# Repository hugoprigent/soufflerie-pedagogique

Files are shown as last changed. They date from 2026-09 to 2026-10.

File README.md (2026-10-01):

# Soufflerie pédagogique — ENSAM, 2026

Cette soufflerie de table permet d'observer l'écoulement autour d'une maquette et d'étudier la commande du ventilateur, la mesure de force et l'acquisition vidéo sur Raspberry Pi. Le dépôt contient les modèles 3D, le logiciel et la documentation du banc.

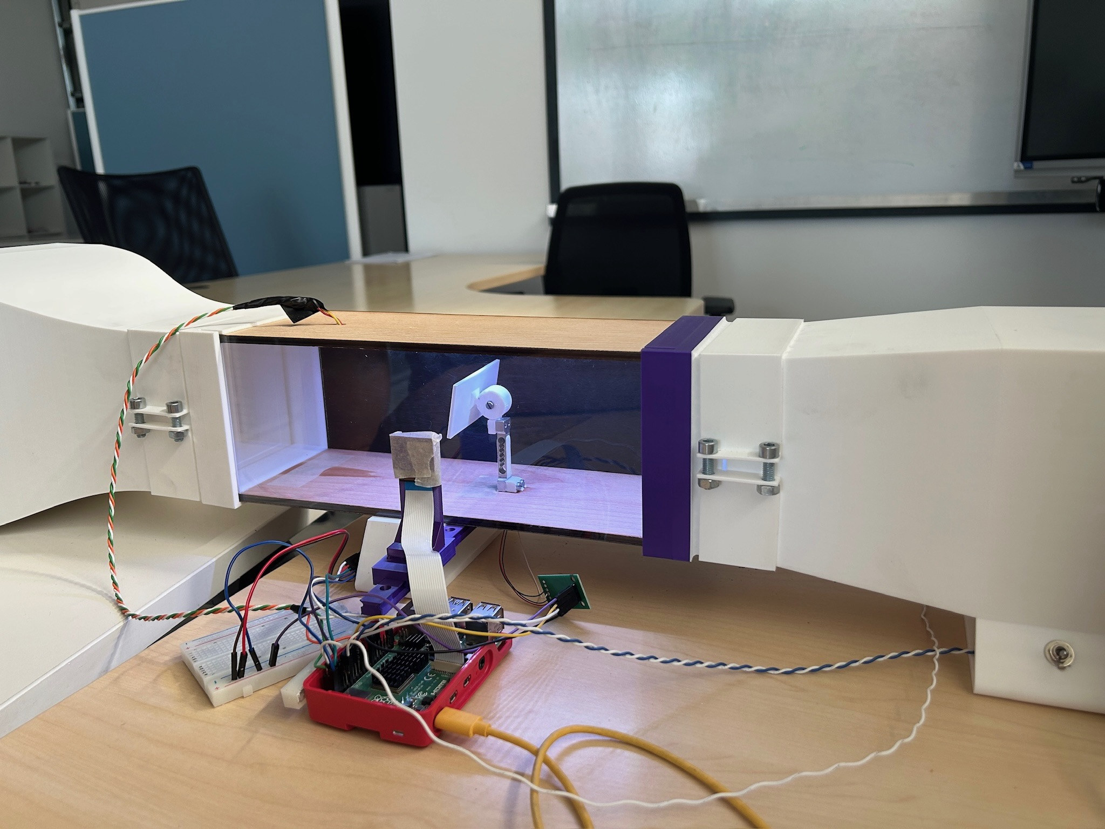
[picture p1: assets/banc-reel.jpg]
Soufflerie pédagogique avec section d'essai transparente


*La soufflerie avec sa section d'essai et son instrumentation.*

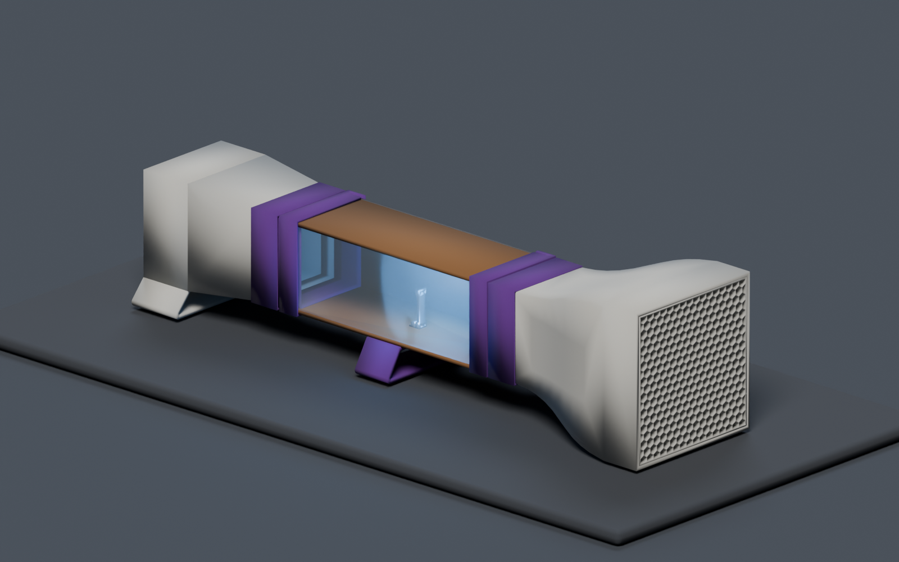
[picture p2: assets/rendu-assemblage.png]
Modèle 3D de la soufflerie


*Modèle 3D de la soufflerie : conduits, section d'essai et supports.*

## Vidéo de présentation

[Voir la soufflerie en vidéo sur YouTube](https://youtu.be/92m-7GADWI4).

## Le projet en bref

| Domaine | Ce qui est disponible |
| --- | --- |
| Mécanique | [Modèle 3D de la soufflerie](cad/assemblage-onshape.step), [23 modèles 3D des pièces](cad/step/), [modèle Blender](cad/rendu-assemblage.blend) et [guide de fabrication](cad/README.md) |
| Électronique | Raspberry Pi, ventilateur, cellule de charge et caméra ; [schéma de câblage](docs/schema-cablage.svg) et [documentation électronique](docs/electronique-cablage.md) |
| Logiciel | [Supervision Python](software/) : PWM et tachymètre, acquisition de force, caméra et traitement d'image, interface HTTP et export CSV |
| Données | [Un export de session](examples/session-2026-05-28.csv) avec [explication des colonnes et limites](docs/donnees-et-limites.md) |

Le banc comporte une section d'essai visible entre un convergent et un diffuseur. La maquette se place dans la veine ; la chaîne de force passe par une cellule de charge et le convertisseur HX711. Le tableau de bord affiche les signaux et permet la commande et l'enregistrement. La caméra sert à la visualisation et à un traitement de flux optique. Les valeurs de vitesse et les coefficients dérivés exigent une calibration indépendante avant toute interprétation quantitative.

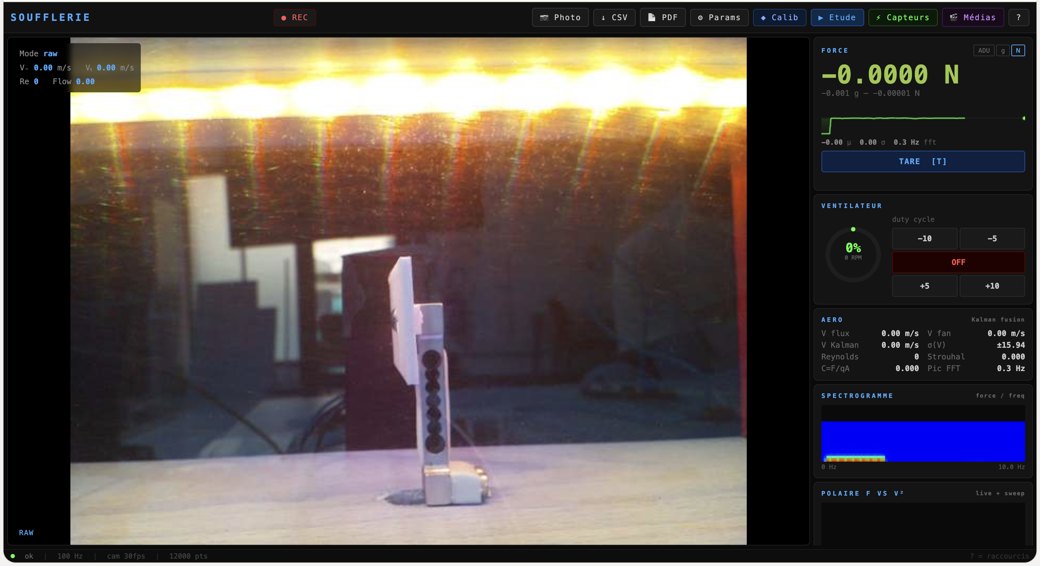
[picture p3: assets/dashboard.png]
Capture du tableau de bord avec retour caméra


*Capture du 28 mai 2026 : le ventilateur est à l'arrêt sur cette image.*

## Parcourir le dépôt

- [Reproduire le projet](docs/reproduire-le-projet.md) : fichiers 3D, nomenclature de reprise, ordre de fabrication, montage et points à relever sur le prototype.
- [CAO et fabrication](cad/README.md) : modèles de l'ensemble et des pièces, repères pour la fabrication.
- [Mécanique et assemblage](docs/mecanique-fabrication.md) : sous-ensembles visibles, ordre de montage proposé et vérifications avant fabrication.
- [Électronique et câblage](docs/electronique-cablage.md) : composants, connexions et broches du Raspberry Pi.
- [Installation et utilisation](docs/installation-utilisation.md) : environnement Raspberry Pi, lancement, accès local et sécurité réseau.
- [Données et limites](docs/donnees-et-limites.md) : ce que l'export permet d'examiner et ce qu'il ne valide pas.
- [Vérifications et compléments](docs/publication.md) : licence, câblage réel et validation matérielle.

## Calibration et accès

La vitesse d'air et les coefficients aérodynamiques affichés nécessitent un étalonnage indépendant.

Le serveur écoute par défaut sur `127.0.0.1:8080`. L'accès depuis un autre appareil doit être activé explicitement et limité à un réseau maîtrisé : l'application ne comporte pas d'authentification. Voir le [guide d'utilisation](docs/installation-utilisation.md).

## Réutilisation

Aucune licence de réutilisation n'est encore attribuée au code, à la documentation, aux photos ou aux modèles 3D. L'absence de fichier de licence ne vaut pas autorisation de réutilisation.

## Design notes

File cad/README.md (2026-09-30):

# CAO de la soufflerie

## Modèles 3D

- [Modèle 3D complet](assemblage-onshape.step) : soufflerie assemblée avec les composants à leur place.
- [23 modèles 3D des pièces](step/) : géométrie de chaque pièce de la soufflerie.

Le modèle complet montre la disposition des sous-ensembles. Les modèles individuels permettent d'examiner les pièces séparément.

Le [rendu 3D](../assets/rendu-assemblage.png) présente la soufflerie assemblée. Le [modèle Blender](rendu-assemblage.blend) permet de consulter cette vue en 3D. Les matériaux, fixations et tolérances de fabrication sont à préciser sur les plans des pièces.

## Pièces individuelles disponibles

Les noms des fichiers identifient notamment le cône de concentration, ses alvéoles, les deux diffuseurs, la fenêtre, les plaques de la veine, les pieds, les jonctions, les supports de caméra et de cellule de charge, un rail, une glissière et les volumes de représentation du ventilateur, de la caméra et de la cellule. Les suffixes `(1)` ne prouvent pas qu'il s'agit de variantes ou de pièces à fabriquer en double.

Certains modèles représentent des composants achetés ou des volumes d'encombrement. **Ne pas imprimer ou usiner l'ensemble des 23 fichiers sans tri.** La [nomenclature](../docs/mecanique-fabrication.md) détaille les pièces et sous-ensembles ; quantité, matériau et procédé doivent être déterminés pour chaque pièce à fabriquer.

## Pour fabriquer ou modifier

1. Ouvrir l'assemblage entier dans un logiciel CAO prenant en charge STEP AP242 et vérifier l'échelle, l'orientation, les corps et les interférences.
2. Comparer les zones de fixation et la section d'essai avec la photo du banc réel. Les modèles ne définissent ni tolérances, ni paramètres d'impression, ni ordre de montage.
3. Séparer les pièces fabriquées des composants commerciaux et contrôler chaque cote utile avant l'usinage ou l'impression.
4. Si une modification est faite dans Onshape, conserver la révision et réexporter à la fois l'assemblage et les pièces concernées.

Le lien Onshape éditable, la révision exacte, les matériaux pièce par pièce et les plans cotés restent à ajouter après vérification.

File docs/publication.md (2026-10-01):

# Vérifications et compléments à apporter

Ce dépôt présente le projet et ses fichiers de reprise. Les points suivants restent à décider ou à vérifier pour permettre une reproduction fidèle et une réutilisation claire :

1. **Licence et droits** — choisir une licence adaptée au code, aux modèles, aux textes et aux photos ; confirmer les droits de publication des éléments mécaniques.
2. **Câblage réel** — résoudre GPIO23/24 contre GPIO5/6 pour le HX711, déterminer la tension admise par la carte exacte et confirmer l'étage de commande du ventilateur. Une photo du montage et un relevé hors tension sont nécessaires.
3. **CAO** — vérifier l'assemblage AP242 dans une CAO, la révision Onshape, les interférences, les quantités et les droits attachés aux modèles de composants commerciaux. Ajouter le lien Onshape éditable s'il doit être public.
4. **Installation** — refaire l'installation sur un Raspberry Pi OS identifié et exécuter une démonstration contrôlée avec caméra, PWM, tachymètre, HX711 et export CSV.
5. **Mesure** — documenter les références de calibration, répétabilité et incertitudes avant de présenter des performances ou des coefficients expérimentaux.
6. **Visuels** — relire les photos pour tout élément personnel ou institutionnel visible ; la photo présente ici a été nettoyée de ses métadonnées EXIF.

L'archive documentaire privée, les factures, les paniers fournisseurs, les rapports de travail comportant des résultats non établis et les documents de tiers ne font pas partie du dépôt.

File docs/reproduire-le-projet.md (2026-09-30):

# Reproduire la soufflerie

Ce guide rassemble les fichiers et les contrôles nécessaires pour refaire un banc de même architecture. La [photo du prototype](../assets/banc-reel.jpg) et l'[assemblage STEP](../cad/assemblage-onshape.step) montrent l'état documenté ; ils ne donnent pas encore un plan de fabrication entièrement coté ni un câblage certifié. Conserver la traçabilité des choix faits lors d'une reproduction.

## Dossier de départ

| Besoin | Fichier | Usage |
| --- | --- | --- |
| Position des pièces | [Assemblage STEP](../cad/assemblage-onshape.step) | Ouvrir dans un logiciel CAO, inspecter les interfaces et mesurer les cotes utiles. |
| Géométrie de chaque pièce | [23 STEP séparés](../cad/step/) | Préparer les plans, l'impression ou l'usinage selon la pièce. |
| Aspect et vue d'ensemble | [Photo](../assets/banc-reel.jpg) et [modèle 3D](../assets/rendu-assemblage.png) | Voir la soufflerie et ses principaux sous-ensembles. |
| Logiciel | [Tableau de bord et modules](../software/) | Reprendre les fonctions GPIO, caméra, affichage et export. |
| Câblage | [Schéma de reprise](schema-cablage.svg) et [notes électriques](electronique-cablage.md) | Relever les connexions réelles puis établir un schéma final. |

## Nomenclature de reprise

Les quantités des pièces CAO sont à extraire de l'assemblage positionné, et les références achetées à lire sur le banc. Les éléments ci-dessous forment une **liste de familles**, pas un panier d'achat validé.

| Famille | Éléments identifiés | À renseigner avant achat ou fabrication |
| --- | --- | --- |
| Conduits et veine | Cône de concentration, alvéoles, diffuseur, jonctions, plaques dessus/dessous/fond, fenêtre, colliers | Dimensions internes, matière, épaisseur, procédé, état de surface, étanchéité |
| Structure et mesure | Pieds, rail, glissière, support de cellule de charge, support et maintien caméra | Positions, tolérances d'ajustement, visserie par liaison, reprise des efforts |
| Ventilation | Ventilateur représenté comme « 120x12x38 » dans le nom d'un STEP | Référence réelle, dimensions vérifiées, tension, courant, nombre de fils, brochage |
| Acquisition | Raspberry Pi, caméra, cellule de charge, carte HX711 | Référence des cartes et connecteurs, plage de mesure, tension et niveaux logiques |
| Éléments éventuels | Capteur BMP280/BME280, encodeur Modulino, LED | Présence réelle et nécessité pour la version à refaire |
| Alimentation et liaisons | Alimentations adaptées, fils, connecteurs, protection, fixations | Schéma électrique final, courant disponible, masse, isolation et cheminement des câbles |

Une nomenclature historique cite une fenêtre en polycarbonate et de la visserie M2, M3 et M5. Ces indications doivent être recoupées avec la version réellement fabriquée ; le dépôt ne donne pas encore les longueurs ni les quantités de vis.

## Séquence de reproduction

1. **Définir la version.** Comparer le [STEP d'assemblage](../cad/assemblage-onshape.step) à la photo. Lister les pièces à fabriquer, les pièces achetées et les écarts observés.
2. **Extraire les plans.** Mesurer dans la CAO les sections d'entrée et d'essai, les interfaces des conduits, l'épaisseur de fenêtre, les trous, les positions de rail et les dégagements autour du ventilateur et de la maquette. Ajouter tolérances et matériaux à des plans d'atelier avant fabrication.
3. **Préparer les pièces.** Utiliser les STEP séparés selon le procédé retenu. Faire un montage à blanc des plaques, de la fenêtre, des jonctions et des conduits ; vérifier alignement, étanchéité et accès à la section d'essai.
4. **Installer l'instrumentation.** Monter la cellule de charge sans effort parasite, puis caméra et éclairage. Vérifier que les fils ne traversent pas le flux ou ne touchent pas les pièces mobiles.
5. **Relever l'électricité.** Photographier les références et sérigraphies des cartes. Hors tension, suivre chaque fil du ventilateur, du HX711, de la cellule, de la caméra et du GPIO. Compléter le [schéma de reprise](schema-cablage.svg) en un schéma validé pour les composants choisis.
6. **Vérifier avant mise sous tension.** Confirmer polarités, alimentation séparée du moteur, masse de référence, niveaux logiques, protections, continuité et absence de court-circuit. Faire contrôler ce relevé par une personne compétente.
7. **Installer le logiciel.** Suivre le [guide Raspberry Pi](installation-utilisation.md), adapter les GPIO et les références dans `software/config.py`, puis tester les périphériques un par un avant de lancer l'application complète.
8. **Étalonner et documenter.** Tare et masses connues pour la chaîne de force ; référence indépendante pour la vitesse. Conserver les valeurs d'étalonnage, le montage, la date et les incertitudes avec les [données](donnees-et-limites.md).

## Informations à compléter pour une réplique fidèle

- Cotes critiques, tolérances, matières, procédés et fichiers de plans cotés.
- Nomenclature avec quantités, références commerciales, visserie et photos de chaque connexion.
- Schéma électrique vérifié du banc, surtout tension du HX711, niveau du tachymètre et mode de commande du ventilateur.
- Procédure d'étalonnage avec étalons, résultats et incertitudes ; essais sur Raspberry Pi et sur le banc assemblé.

Ces lacunes sont indiquées pour éviter qu'une hypothèse issue du logiciel ou d'une ancienne note soit prise pour une mesure sur le prototype.

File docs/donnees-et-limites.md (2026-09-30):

# Données et limites des essais

Le fichier [`examples/session-2026-05-28.csv`](../examples/session-2026-05-28.csv) est un export de session existant. Les lignes `#` enregistrent des paramètres au moment de l'export ; la ligne suivante nomme les colonnes. Il permet de voir la structure des acquisitions, sans constituer à lui seul une validation métrologique.

| Colonne | Sens dans l'export |
| --- | --- |
| `t_s` | Temps enregistré par l'acquisition, en secondes |
| `duty_pct` | Consigne PWM du ventilateur |
| `fan_rpm` | Régime déduit du tachymètre, sous réserve d'une lecture correcte |
| `delta_adu` | Signal HX711 après retrait de l'offset, en unités numériques |
| `force_g`, `force_N` | Force calculée avec la tare et l'échelle enregistrées |
| `flow_mag_px` | Grandeur issue du traitement d'image |
| `airspeed_flow_ms` | Estimation de vitesse issue de l'image et de sa calibration |
| `airspeed_fan_ms` | Estimation de vitesse issue du modèle ventilateur |

Dans les premières lignes de cet export, `duty_pct` vaut 60 tandis que `fan_rpm` et les deux estimations de vitesse valent zéro. Cette divergence impose de contrôler le tachymètre, l'état du ventilateur et les temps de transition avant d'utiliser ces colonnes pour conclure sur un essai. Les métadonnées de calibration ne prouvent pas que la chaîne a été étalonnée avec une référence traçable.

Le régime du ventilateur ne donne pas directement la vitesse locale dans la veine. Le flux optique dépend de l'échelle en pixels, de l'éclairage, du traceur visible et du plan observé. La mesure de force dépend notamment de la tare, de la rigidité du montage, des contacts parasites et des perturbations électriques. Aucune précision, plage utile, répétabilité ni coefficient aérodynamique validé n'est revendiqué ici.

Des documents historiques mêlent données enregistrées, valeurs théoriques, corrections et simulations. Ils n'ont pas été repris comme preuves expérimentales. Une suite de validation devrait conserver séparément les lectures brutes, les références de calibration, les transformations, les incertitudes et les conditions de montage, puis comparer plusieurs essais reproductibles.

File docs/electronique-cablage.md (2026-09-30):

# Électronique et câblage

Schéma de reprise du câblage avec connexions du logiciel et points incertains

Le [schéma de reprise en SVG](schema-cablage.svg) accompagne le relevé du prototype. Les traits pleins montrent les affectations déclarées par le code ; les pointillés signalent les alimentations et connexions à confirmer avant de construire un circuit. Il ne constitue pas un schéma de mise sous tension validé.

## Chaîne fonctionnelle

```mermaid
flowchart LR
  P[Raspberry Pi] -->|PWM| V[Ventilateur]
  V -->|Tachymètre| P
  C[Cellule de charge] --> H[HX711] -->|DT / SCK| P
  K[Caméra] -->|CSI| P
  B[Capteur BMP280/BME280] -. I²C optionnel .-> P
  M[Encodeur Modulino] -. I²C optionnel .-> P
  P --> I[Interface web et CSV]
```

Le logiciel actuel utilise directement les GPIO pour lire le HX711 et commander le ventilateur. Il prévoit également un bus I²C et un ruban LED SPI. La présence et le branchement effectifs de tous les modules optionnels n'ont pas été revérifiés.

## Broches déclarées par le code actuel

| Fonction | GPIO BCM | Broche physique Raspberry Pi | Source |
| --- | ---: | ---: | --- |
| PWM ventilateur | 18 | 12 | `software/config.py` |
| Tachymètre ventilateur | 17 | 11 | `software/config.py` |
| HX711 DT | 23 | 16 | `software/config.py` |
| HX711 SCK | 24 | 18 | `software/config.py` |
| I²C SDA / SCL | 2 / 3 | 3 / 5 | Bus Raspberry Pi, modules I²C du code |
| Ruban LED SPI | 10 | 19 | `software/src/led_control.py` |

**Divergence importante :** des notes et rapports historiques placent HX711 DT/SCK sur GPIO5/6, tandis que le code courant et une note de connexions plus récente indiquent GPIO23/24. Une ancienne note demande une alimentation HX711 à 3,3 V ; une autre à 5 V pour un module supposé régulé. Le type exact de carte HX711 et le câblage réel ne sont pas établis par les sources disponibles. **Ne brancher le module ni à 3,3 V ni à 5 V d'après ce seul document.** Vérifier la référence, le schéma ou la sérigraphie de la carte et les niveaux logiques avant mise sous tension, puis aligner `config.py` sur le banc.

## Alimentations et interfaces à contrôler

- Le ventilateur a une alimentation distincte de celle du Raspberry Pi. Confirmer sa tension et son brochage sur la référence réellement montée. Ne pas alimenter le moteur depuis un GPIO.
- Les notes diffèrent sur l'étage de commande : PWM direct d'un ventilateur à quatre fils dans la note récente, MOSFET dans des documents plus anciens. Identifier le ventilateur et le montage présents avant de reproduire le circuit.
- Vérifier la masse de référence commune des signaux de commande, les niveaux d'entrée du tachymètre et l'état du ventilateur en cas de perte de PWM.
- La caméra se connecte à l'interface CSI du Pi ; l'orientation de la nappe doit être vérifiée sur les connecteurs effectivement utilisés.
- Les modules BMP280/BME280 et Modulino sont prévus sur le bus I²C ; vérifier leurs adresses et leur présence. Le capteur de pression seul ne suffit pas à établir une vitesse locale validée.

Aucun schéma historique n'est présenté comme plan de câblage définitif : certains portent GPIO5/6 et des hypothèses d'alimentation incompatibles avec les notes plus récentes. Le prochain contrôle utile est une photo nette de chaque carte, de ses fils et de l'en-tête GPIO, suivie d'un relevé point à point hors tension.

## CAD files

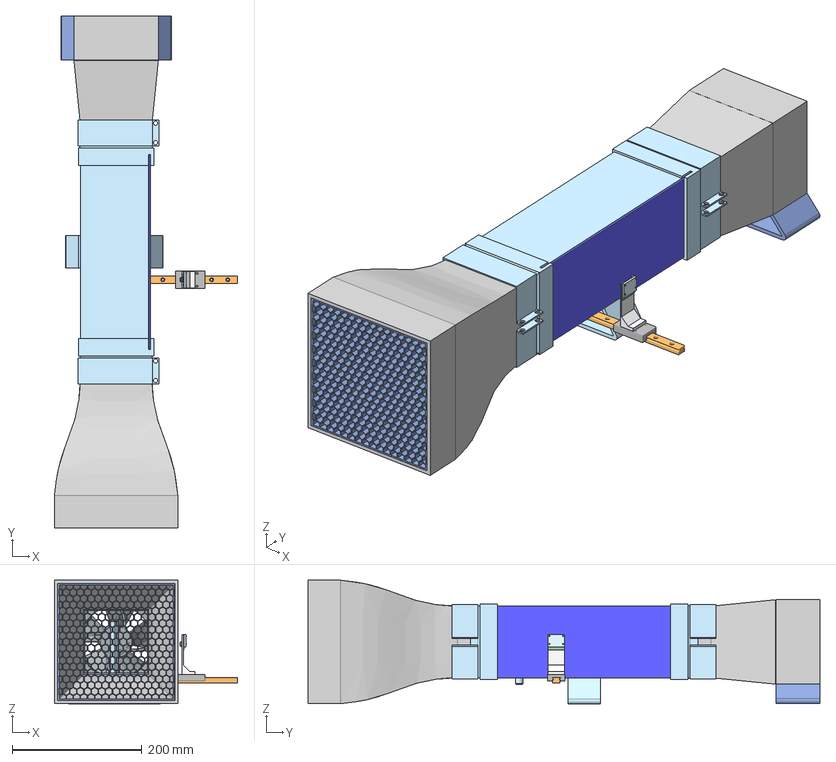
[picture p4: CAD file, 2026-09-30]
cad/assemblage-onshape.step
281.9 x 788.0 x 190.2 mm
Rail
Plaque dessus
Diffuseur x 2
Fenêtre
Alvéoles concentration
Jonction droite
Collier de serrage x 2
120x12x38 fan
Maintien caméra
Caméra
Support caméra
Glissière
Plaque dessous
Plaque fond
Pied diffuseur
Support cellule de charge
Jonction gauche
Cône de concentration
Alvéoles diffuseur
Cellule de charge

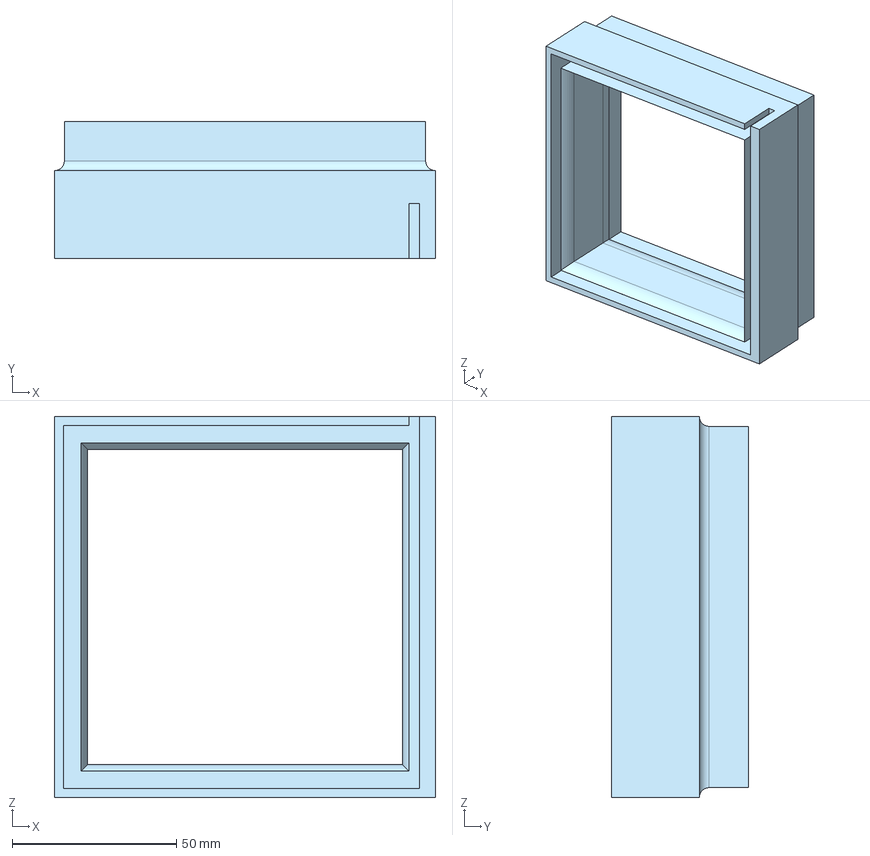
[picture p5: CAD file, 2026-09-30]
cad/step/Assemblage V2 - Jonction droite.step
116.0 x 41.8 x 116.0 mm

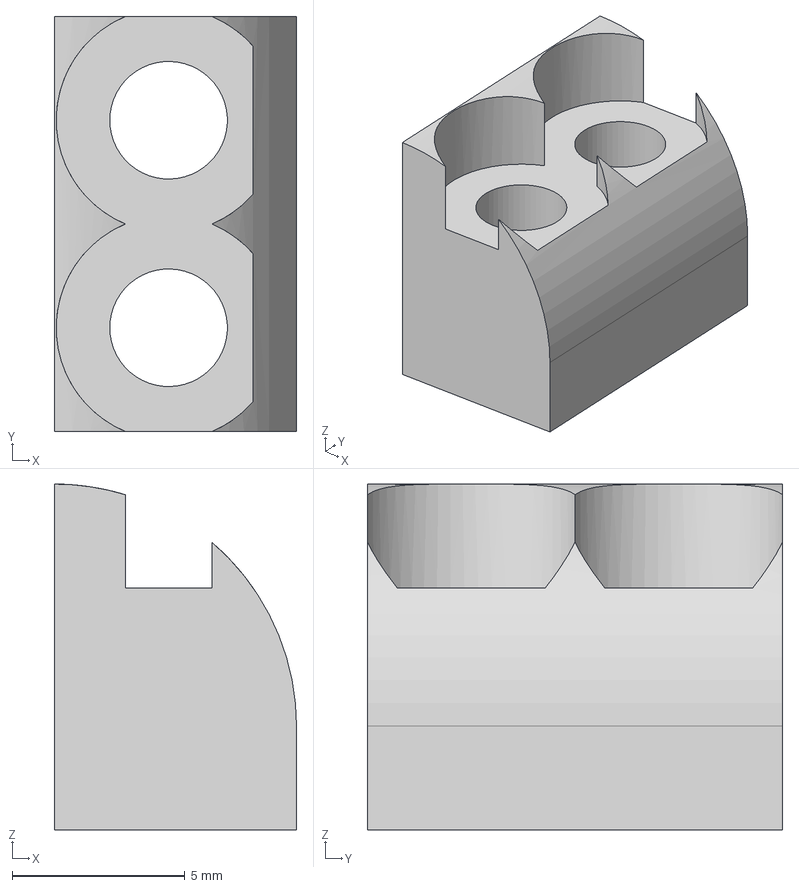
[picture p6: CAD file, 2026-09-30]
cad/step/Assemblage V2 - Support cellule de charge.step
7.00 x 12.0 x 10.0 mm

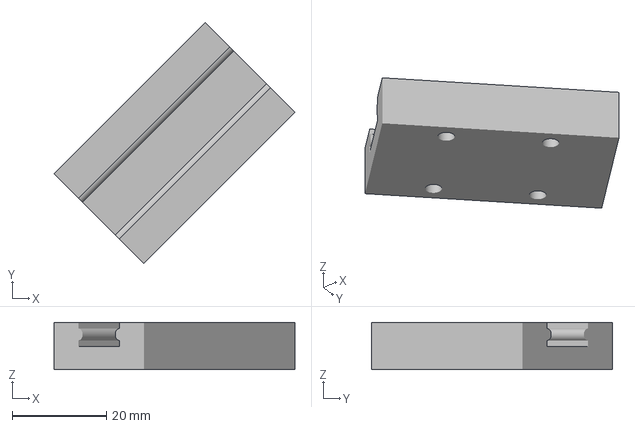
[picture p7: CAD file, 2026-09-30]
cad/step/Assemblage V2 - Glissière.step
51.2 x 51.2 x 10.0 mm

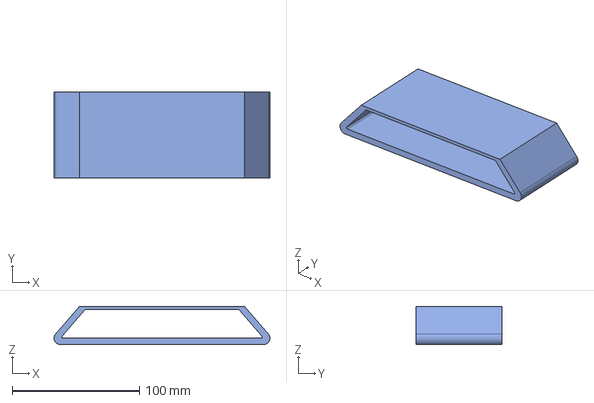
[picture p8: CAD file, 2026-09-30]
cad/step/Assemblage V2 - Pied diffuseur.step
170.0 x 68.0 x 30.0 mm

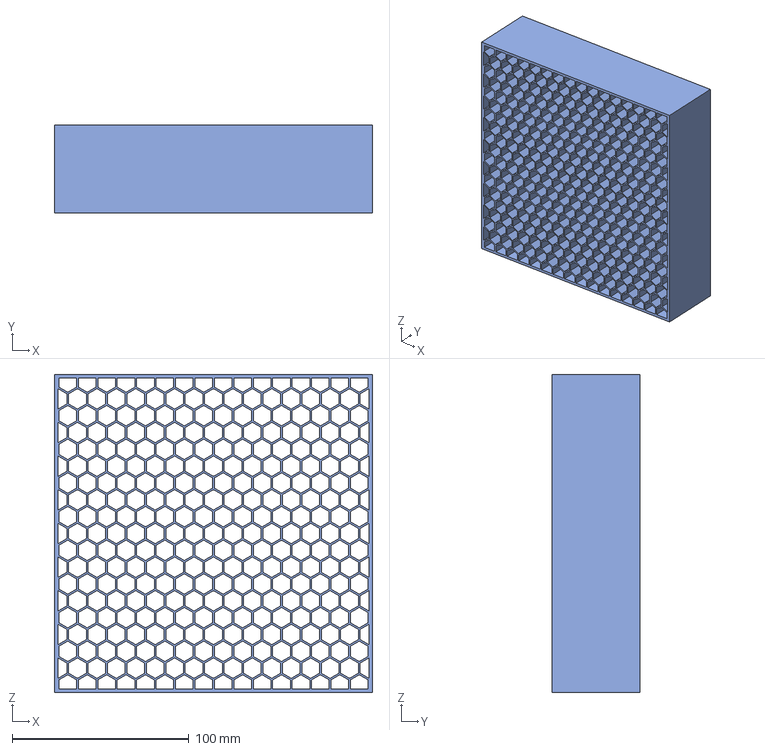
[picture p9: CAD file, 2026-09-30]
cad/step/Assemblage V2 - Alvéoles concentration.step
180.0 x 50.0 x 180.0 mm

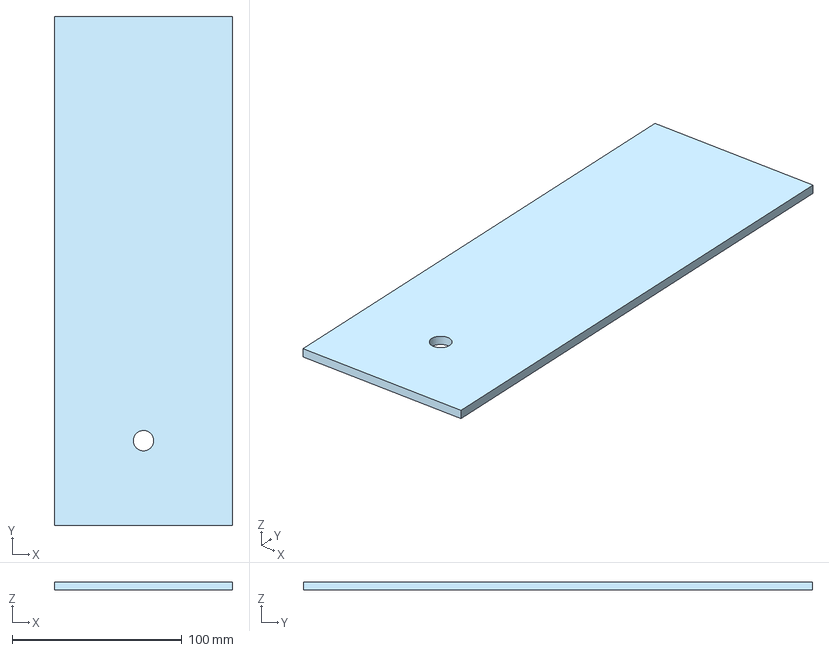
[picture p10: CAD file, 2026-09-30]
cad/step/Assemblage V2 - Plaque dessous.step
105.2 x 300.0 x 5.00 mm

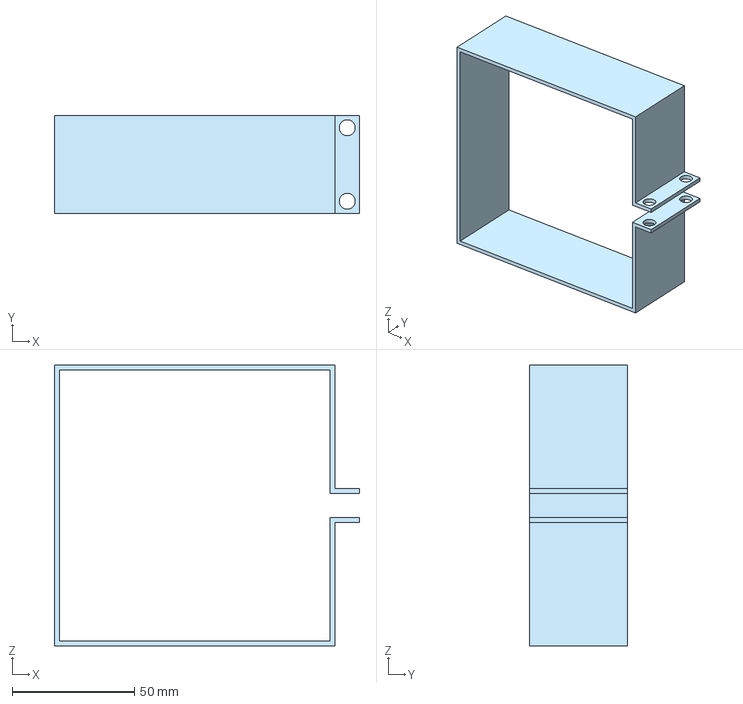
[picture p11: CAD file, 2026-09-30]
cad/step/Assemblage V2 - Collier de serrage.step
124.5 x 40.0 x 114.5 mm

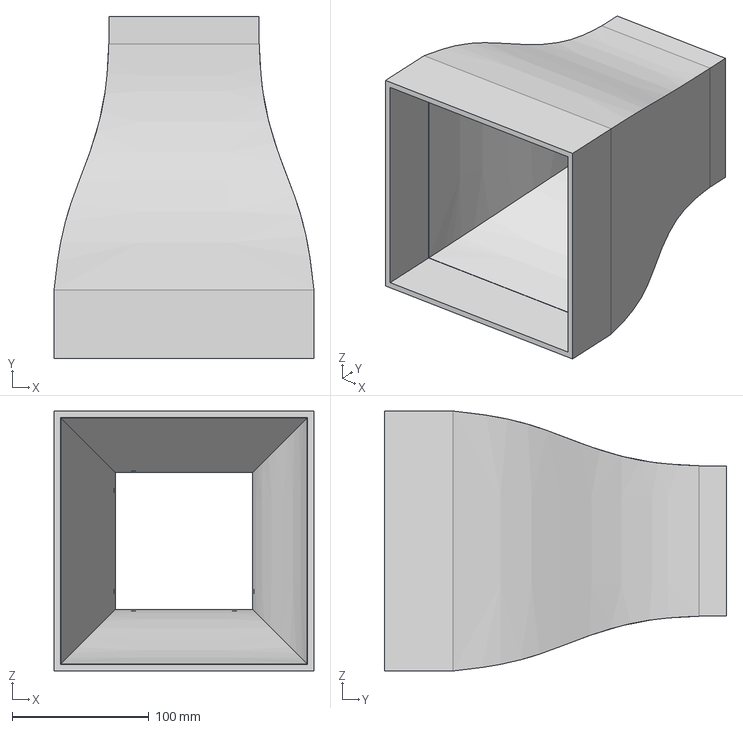
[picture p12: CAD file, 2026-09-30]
cad/step/Assemblage V2 - Cône de concentration.step
190.0 x 250.0 x 190.0 mm

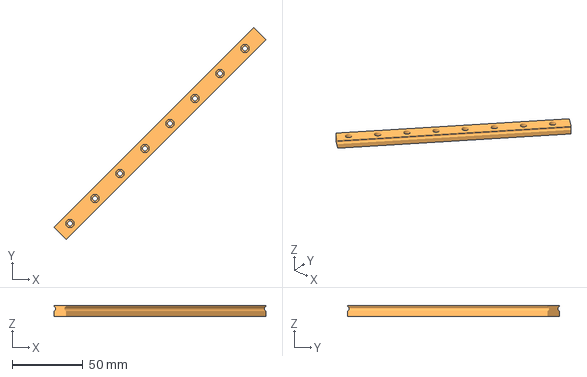
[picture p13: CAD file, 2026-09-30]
cad/step/Assemblage V2 - Rail.step
149.9 x 149.9 x 8.00 mm

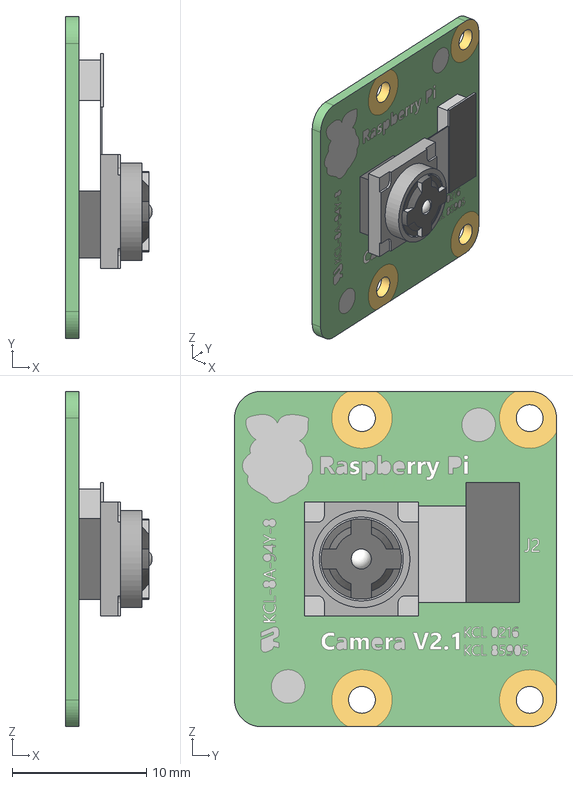
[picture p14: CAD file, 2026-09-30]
cad/step/Assemblage V2 - Caméra.step
6.45 x 24.0 x 25.0 mm

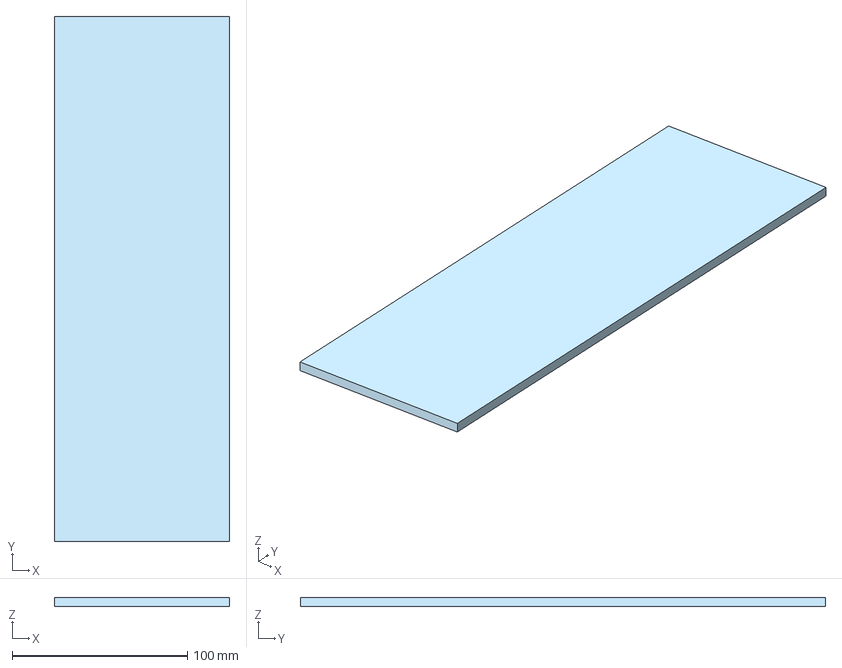
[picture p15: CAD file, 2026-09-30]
cad/step/Assemblage V2 - Plaque fond.step
100.0 x 300.0 x 5.00 mm

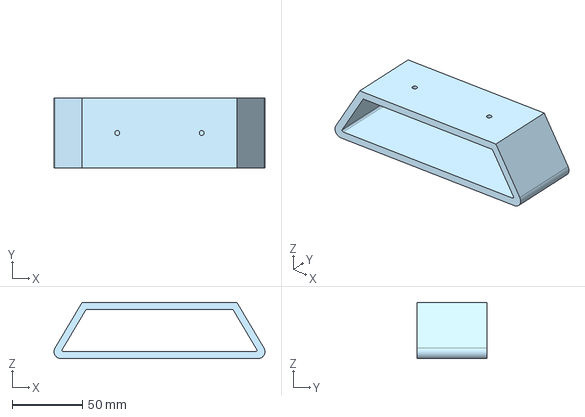
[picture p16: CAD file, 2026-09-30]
cad/step/Assemblage V2 - Pied section d'essai.step
150.0 x 50.0 x 40.0 mm

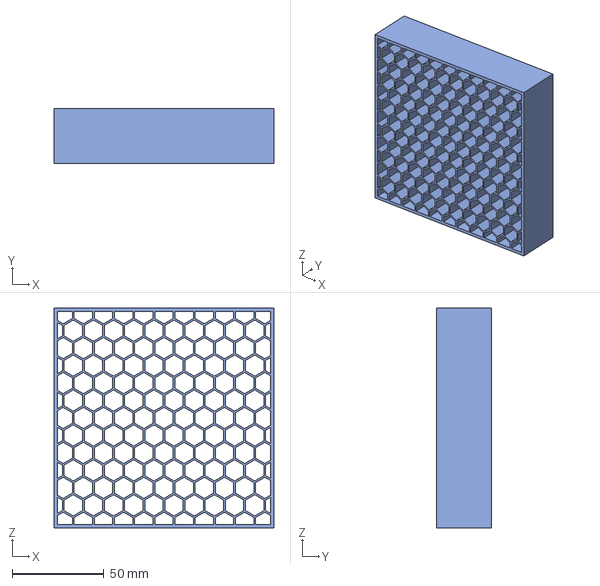
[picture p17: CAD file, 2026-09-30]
cad/step/Assemblage V2 - Alvéoles diffuseur.step
120.0 x 30.0 x 120.0 mm

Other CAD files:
cad/step/Assemblage V2 - Jonction gauche.step
cad/step/Assemblage V2 - Plaque dessus.step
cad/step/Assemblage V2 - 120x12x38 fan.step
cad/step/Assemblage V2 - Maintien caméra.step
cad/rendu-assemblage.blend
cad/step/Assemblage V2 - Cellule de charge.step
cad/step/Assemblage V2 - Collier de serrage (1).step
cad/step/Assemblage V2 - Diffuseur (1).step
cad/step/Assemblage V2 - Diffuseur.step
cad/step/Assemblage V2 - Fenêtre.step
cad/step/Assemblage V2 - Support caméra.step

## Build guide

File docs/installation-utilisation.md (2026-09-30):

# Installation et utilisation sur Raspberry Pi

## Portée

Le point d'entrée est `software/dashboard.py`. Il initialise des GPIO, le ventilateur, la caméra et des boucles d'acquisition dès son lancement. Il ne s'exécute donc pas comme une simple application web sur un ordinateur sans matériel. La procédure ci-dessous est une base de reprise, **non validée sur une image Raspberry Pi OS neuve**.

La [documentation Raspberry Pi OS](https://www.raspberrypi.com/documentation/computers/os.html#use-python-on-a-raspberry-pi) recommande `apt` pour les paquets système et un environnement virtuel pour les dépendances `pip`. La [documentation caméra officielle](https://www.raspberrypi.com/documentation/computers/camera_software.html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) décrit l'installation de Picamera2 via `apt`.

## Préparer le Pi

1. Vérifier le [câblage réel](electronique-cablage.md), en particulier le HX711 et l'étage ventilateur, avant de mettre le banc sous tension.
2. Installer Raspberry Pi OS et activer caméra, I²C et SPI selon les périphériques réellement présents. Vérifier la caméra avec les outils du système avant de lancer le tableau de bord.
3. Installer les modules système nécessaires, par exemple `python3-picamera2`, `python3-opencv`, `python3-numpy`, `python3-matplotlib`, `python3-rpi.gpio`, `python3-spidev`, `python3-venv` et `ffmpeg` pour les conversions vidéo. La disponibilité et la compatibilité de ces paquets dépendent de l'image choisie.
4. Depuis la racine de ce dépôt, créer l'environnement puis installer les dépendances Python restantes :

   ```sh
   python3 -m venv --system-site-packages .venv
   . .venv/bin/activate
   python -m pip install -r software/requirements.txt
   ```

5. Depuis `software/`, vérifier les valeurs de `config.py`, puis lancer `python dashboard.py`. Le répertoire de données est `software/data/` par défaut ; `SOUFFLERIE_DATA_DIR` permet de le déplacer. Les exports et calibrations restent locaux et sont ignorés par Git.

## Accès et sécurité réseau

Par défaut, le serveur écoute sur `127.0.0.1:8080`. Sur le Pi, ouvrir `http://127.0.0.1:8080`. Depuis un poste de confiance, un tunnel SSH permet de conserver cette écoute locale :

```sh
ssh -L 8080:127.0.0.1:8080 utilisateur@adresse-du-pi
```

Ouvrir ensuite `http://127.0.0.1:8080` sur le poste. Pour une démonstration sur un réseau isolé, l'opérateur peut définir `SOUFFLERIE_BIND_HOST=0.0.0.0` avant le lancement. **L'application n'a ni authentification ni chiffrement HTTP** ; cet accès donne aux autres clients du réseau la possibilité de commander le ventilateur, changer la calibration, agir sur des fichiers de session et voir le flux caméra. Ne pas l'exposer à Internet ou à un réseau partagé non maîtrisé. La configuration Wi-Fi depuis l'interface est désactivée par défaut ; elle demande `SOUFFLERIE_ENABLE_WIFI_CONTROL=1` et des droits NetworkManager configurés sur le Pi. Aucun mot de passe administrateur n'est stocké dans le code.

## Utiliser et enregistrer

1. Contrôler l'arrêt initial du ventilateur, l'image caméra et les indicateurs d'erreur.
2. Faire une tare et vérifier l'échelle de la cellule avec une référence connue, sans extrapoler de précision à partir d'une seule masse.
3. Vérifier séparément les estimations de vitesse. Les constantes de `config.py` sont des paramètres de départ, pas un étalonnage du banc assemblé.
4. Commander progressivement le ventilateur, surveiller les pièces libres et enregistrer une session.
5. À la fin, ramener la consigne à zéro, arrêter l'enregistrement et exporter les données.

Les dépendances déclarées par le projet historique utilisaient notamment des versions Python plus anciennes ; elles n'ont pas été réinstallées ni testées sur un Pi pour cette copie. `software/requirements.txt` ne contient que `smbus2`, utilisé pour l'I²C et à installer dans l'environnement virtuel ; les autres imports principaux sont fournis par les paquets système indiqués ci-dessus. Le module `hx711` historique a été retiré des dépendances : le tableau de bord lit le composant par GPIO directement.

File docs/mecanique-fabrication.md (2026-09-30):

# Mécanique et fabrication

## Architecture visible

La photo du prototype montre un convergent et un diffuseur blancs autour d'une section d'essai transparente. Les panneaux supérieur et inférieur paraissent en bois clair, le fond de la veine est sombre, et des éléments de liaison violets ferment les extrémités. Une maquette est portée dans la veine ; une caméra et un éclairage permettent l'observation. Les fils et le boîtier électronique restent apparents.

L'[assemblage STEP](../cad/assemblage-onshape.step) est la meilleure source disponible pour l'agencement CAO. Les [23 pièces STEP](../cad/step/) servent à examiner les formes séparément. Les modèles ne fournissent pas, à eux seuls, des plans de fabrication cotés avec tolérances ou une nomenclature validée.

## Repères de composants

Une nomenclature de l'assemblage historique cite un cône de concentration, des alvéoles, une section d'essai, deux colliers, un diffuseur, une fenêtre en polycarbonate, un pied et de la visserie M2, M3 et M5. Cet état historique peut différer de l'export V2, qui comporte par exemple plusieurs plaques, supports et jonctions. Il sert de repère pour le tri, **pas de liste de commande vérifiée**.

| Sous-ensemble | Fichiers ou éléments à examiner | Vérification nécessaire |
| --- | --- | --- |
| Entrée et sortie | Cône de concentration, alvéoles, diffuseur, pied diffuseur | Sens du flux, raccords, fixation au ventilateur |
| Veine d'essai | Plaques, fenêtre, jonctions, colliers | Dimensions internes, étanchéité, accès à la maquette |
| Instrumentation | Rail, glissière, support de cellule de charge, support et maintien caméra | Alignement, absence de contact parasite avec la veine |
| Composants achetés | Ventilateur, caméra, cellule de charge | Références exactes et encombrement réel |

## Ordre de montage proposé à vérifier sur le banc

1. Identifier les pièces réellement fabriquées et les pièces commerciales dans l'assemblage CAO.
2. Assembler à blanc les panneaux et la fenêtre de la veine ; contrôler l'alignement et les interfaces avec le convergent et le diffuseur.
3. Installer les supports, rail, maquette et cellule de charge sans contrainte latérale ni contact non prévu avec les parois.
4. Poser caméra et éclairage en conservant l'accès à la section d'essai.
5. Fixer ventilateur et conduits, puis contrôler le sens du flux, les dégagements des pales et l'absence de pièces libres.
6. Faire contrôler le câblage et les alimentations avant la mise sous tension.

Cet ordre décrit une méthode de préparation ; ce n'est pas un protocole d'atelier validé. Il manque encore les cotes critiques, tolérances, visserie par emplacement, paramètres d'impression et détails d'étanchéité.

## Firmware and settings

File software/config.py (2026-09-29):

# GPIO (BCM)
PIN_FAN_PWM = 18
PIN_FAN_TACH = 17
PIN_HX711_DT = 23
PIN_HX711_SCK = 24

# Modulino Knob I2C
MODULINO_I2C_ADDR = 0x3A

# Capteur pression BMP280 (I2C, même bus que Modulino)
# Câblage : SDA→GPIO2/Pin3, SCL→GPIO3/Pin5, VCC→3.3V, GND→GND, SDO→GND
PRESSURE_I2C_BUS  = 1
PRESSURE_I2C_ADDR = 0x76     # SDO→GND=0x76 ; SDO→VCC=0x77

# PWM ventilateur
PWM_FREQUENCY = 25000
PWM_MIN_DUTY = 20
PWM_MAX_DUTY = 80

# HX711 — calibration (ADU/g). Tare = offset, scale = ADU par gramme.
HX711_OFFSET = 0
HX711_SCALE = 1.0
FORCE_FILTER_WINDOW = 10     # fenetre moyenne glissante (echantillons)
FORCE_SAMPLE_HZ = 20         # freq boucle force
SUPPORT_DRAG_N = 0.0         # trainee aero du support seul (tare aero, N)

# Geometrie tunnel (variables — modifier si la section change)
A_FAN_M2  = 0.0144    # m² — section ventilateur 120×120 mm (0.12*0.12)
A_TEST_M2 = 0.0100    # m² — section d'essai     100×100 mm (0.10*0.10)
# Rapport de contraction (continuité Q = V_fan*A_fan = V_test*A_test)
CONTRACTION = A_FAN_M2 / A_TEST_M2   # = 1.44

# Profil et aero (utilise pour CL/CD/Re/St)
AIR_DENSITY = 1.204          # kg/m^3 @ 20 C
AIR_VISCOSITY = 1.82e-5      # Pa.s
PROFILE_CHORD_M = 0.10       # corde (m)
PROFILE_SPAN_M = 0.10        # envergure (m) — section d'essai 100x100 mm
PROFILE_AOA_DEG = 0.0        # angle d attaque par defaut

# Vent estime depuis le ventilateur : V = FAN_KV * RPM + FAN_K0
#
# Calibration depuis fiche technique Orion Fans OD1238 VXC (12V) :
#   A_fan = 120x120 mm = 0.0144 m²   (1 CFM = 4.71947e-4 m³/s)
#   LB : 3000 RPM -> Q=0.06589 m³/s -> V_section=Q/A_TEST=6.589 m/s -> KV=0.002196
#   MB : 4000 RPM -> Q=0.08898 m³/s -> V_section=Q/A_TEST=8.898 m/s -> KV=0.002225
#   HB : 5000 RPM -> Q=0.10666 m³/s -> V_section=Q/A_TEST=10.666 m/s-> KV=0.002133
#   Moyenne : KV_section ≈ 0.00219 m/s/RPM = KV_fan * CONTRACTION (1.44)
#
#   Note : valeurs a Q_max (ΔP=0). En tunnel reel avec pertes η<1 → calibrer
#   empiriquement via /calibrate (section "Calibration pression BMP280").
FAN_KV = 0.00219             # m/s par RPM — section d'essai 100×100 mm, Q_max
FAN_K0 = 0.0                 # offset (m/s) : 0 car modele lineaire par l'origine

# Camera
CAM_WIDTH = 1280
CAM_HEIGHT = 960
CAM_FPS = 30
CAM_PX_PER_M = 1000.0        # calibration px/m (a regler avec une regle dans la scene)

# Camera controles (picamera2 set_controls)
CAM_BRIGHTNESS = 0.0         # [-1, 1]
CAM_CONTRAST = 1.0           # [0, 32] 1 = neutre
CAM_SATURATION = 1.0         # [0, 32] 1 = neutre
CAM_AE_ENABLE = True
CAM_AWB_ENABLE = True
CAM_EXPOSURE_US = 10000      # si AE off
CAM_GAIN = 1.0               # si AE off

# Flow (Farneback) — regle pour fumee lente
FLOW_PYR_SCALE = 0.5
FLOW_LEVELS = 5       # plus de niveaux = detecte les grands deplacements
FLOW_WINSIZE = 25     # fenetre plus large = plus sensible aux petits gradients
FLOW_ITERATIONS = 5   # plus d'iterations = plus precis
FLOW_POLY_N = 7       # voisinage polynomial plus grand
FLOW_POLY_SIGMA = 1.5
FLOW_FLAGS = 0

# Logging
DATA_DIR = "data/raw"
VIDEO_DIR = "data/videos"
CSV_HEADER = ["timestamp", "duty_pct", "rpm", "force_N", "airspeed_ms", "flow_mag", "frame_idx"]

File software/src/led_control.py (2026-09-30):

"""Controleur ruban LED WS2812B via SPI (GPIO10 / MOSI / pin 19).

Utilise /dev/spidev0.0 ; l'utilisateur du Pi doit avoir accès au groupe spi.
Encodage : 1 SPI byte = 1 bit WS2812B a 8 MHz.
  0-bit : 0xC0 -> T0H=250ns  T0L=750ns
  1-bit : 0xF8 -> T1H=625ns  T1L=375ns
"""

import math
import threading
import time

SPI_BUS     = 0
SPI_DEVICE  = 0
SPI_SPEED   = 8_000_000   # 8 MHz

_B0 = 0xC0   # WS2812B 0-bit : 2 high + 6 low
_B1 = 0xF8   # WS2812B 1-bit : 5 high + 3 low
_RESET_BYTES = 60   # >50 µs de LOW = reset strip


def _encode_pixel(r, g, b):
    """Encode (R,G,B) en 24 bytes SPI (ordre GRB WS2812B)."""
    out = bytearray(24)
    idx = 0
    for byte in (g, r, b):
        for bit in range(7, -1, -1):
            out[idx] = _B1 if (byte >> bit) & 1 else _B0
            idx += 1
    return out


def _build_frame(pixels):
    buf = bytearray()
    for r, g, b in pixels:
        buf += _encode_pixel(r, g, b)
    buf += bytearray(_RESET_BYTES)
    return bytes(buf)


def _hsv_to_rgb(h_deg, s, v):
    h = (h_deg % 360) / 60.0
    i = int(h)
    f = h - i
    p, q, t = v*(1-s), v*(1-f*s), v*(1-(1-f)*s)
    r, g, b = [(v,t,p),(q,v,p),(p,v,t),(p,q,v),(t,p,v),(v,p,q)][i % 6]
    return int(r*255), int(g*255), int(b*255)


_ENSAM_MAUVE  = (148, 60, 200)  # violet/mauve ENSAM
_ENSAM_ORANGE = (255, 110, 0)   # orange ENSAM
_ENSAM_WHITE  = (230, 230, 255) # blanc chaud


class LedController:
    ANIMATIONS = ("off", "solid", "pulse", "rainbow", "strobe", "wipe", "exposition", "boite_nuit")

    def __init__(self, n_leds=30):
        self.n          = n_leds
        self.animation  = "solid"
        self.color      = (0, 120, 255)
        self.brightness = 80           # 0-255 (applique en scale sur les couleurs)
        self.speed      = 50           # 0-100
        self._lock      = threading.Lock()
        self._spi       = None
        self.error      = ""
        self._startup_done = False

        try:
            import spidev
            spi = spidev.SpiDev()
            spi.open(SPI_BUS, SPI_DEVICE)
            spi.max_speed_hz = SPI_SPEED
            spi.mode = 0
            self._spi = spi
        except Exception as e:
            self.error = str(e)

        threading.Thread(target=self._loop, daemon=True).start()

    @property
    def ok(self):
        return self._spi is not None

    def set(self, **kw):
        with self._lock:
            if "animation"  in kw: self.animation  = kw["animation"]
            if "color"      in kw: self.color       = tuple(kw["color"])
            if "brightness" in kw: self.brightness  = max(0, min(255, int(kw["brightness"])))
            if "speed"      in kw: self.speed       = max(1, min(100, int(kw["speed"])))
            if "n_leds"     in kw: self.n           = max(1, int(kw["n_leds"]))

    def _write(self, pixels):
        if self._spi:
            try:
                self._spi.writebytes2(_build_frame(pixels))
            except Exception as e:
                self.error = str(e)

    def _fill(self, r, g, b):
        bri = self.brightness / 255.0
        self._write([(int(r*bri), int(g*bri), int(b*bri))] * self.n)

    def _run_startup(self):
        """Animation demarrage : wipe bleu ENSAM + eclair arc-en-ciel + fondu vers saved."""
        if not self._spi:
            return
        with self._lock:
            n = self.n
            bri = self.brightness / 255.0
            r_s, g_s, b_s = self.color

        # 1) tout eteint
        self._write([(0, 0, 0)] * n)
        time.sleep(0.15)

        # 2) wipe mauve ENSAM des deux bouts vers le centre
        r0, g0, b0 = _ENSAM_MAUVE
        c_mauve = (int(r0 * bri), int(g0 * bri), int(b0 * bri))
        for step in range(n // 2 + 2):
            pix = [(0, 0, 0)] * n
            for i in range(min(step + 1, n)):
                pix[i] = c_mauve
            for i in range(max(n - step - 1, 0), n):
                pix[i] = c_mauve
            self._write(pix)
            time.sleep(0.025)

        # 3) flash orange ENSAM
        rw, gw, bw = _ENSAM_ORANGE
        self._write([(int(rw * bri), int(gw * bri), int(bw * bri))] * n)
        time.sleep(0.15)
        # flash blanc
        rw2, gw2, bw2 = _ENSAM_WHITE
        self._write([(int(rw2 * bri), int(gw2 * bri), int(bw2 * bri))] * n)
        time.sleep(0.12)

        # 4) burst arc-en-ciel rapide (16 frames)
        for frame in range(16):
            pix = []
            for i in range(n):
                hue = (frame * 22.5 + i * 360 / max(n, 1)) % 360
                rc, gc, bc = _hsv_to_rgb(hue, 1.0, bri)
                pix.append((rc, gc, bc))
            self._write(pix)
            time.sleep(0.04)

        # 5) fondu arco-en-ciel → couleur enregistree (10 frames)
        for step in range(10):
            t_f = step / 9.0
            pix = []
            for i in range(n):
                hue = (16 * 22.5 + i * 360 / max(n, 1)) % 360
                rc, gc, bc = _hsv_to_rgb(hue, 1.0, bri)
                pix.append((
                    int(rc * (1 - t_f) + r_s * bri * t_f),
                    int(gc * (1 - t_f) + g_s * bri * t_f),
                    int(bc * (1 - t_f) + b_s * bri * t_f),
                ))
            self._write(pix)
            time.sleep(0.04)

    def _loop(self):
        self._run_startup()
        self._startup_done = True

        t = 0.0
        wipe_pos = 0
        prev_anim = None

        while True:
            try:
                if not self._spi:
                    time.sleep(0.5)
                    continue

                with self._lock:
                    anim = self.animation
                    r, g, b = self.color
                    bri = self.brightness / 255.0
                    spd = max(0.01, self.speed / 100.0)
                    n   = self.n

                if anim != prev_anim:
                    t = 0.0; wipe_pos = 0
                    prev_anim = anim

                if anim == "off":
                    self._write([(0, 0, 0)] * n)
                    time.sleep(0.2)
                    continue

                elif anim == "solid":
                    self._fill(r, g, b)
                    time.sleep(0.1)
                    continue

                elif anim == "pulse":
                    f = (math.sin(t * math.pi * 2) + 1) / 2
                    self._write([(int(r*bri*f), int(g*bri*f), int(b*bri*f))] * n)
                    t += 0.04 * spd * 3

                elif anim == "rainbow":
                    pixels = []
                    for i in range(n):
                        hue = (t * 360 + i * 360 / max(n, 1)) % 360
                        rc, gc, bc = _hsv_to_rgb(hue, 1.0, bri)
                        pixels.append((rc, gc, bc))
                    self._write(pixels)
                    t += 0.8 * spd
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

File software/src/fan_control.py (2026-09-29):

import time
import threading
import RPi.GPIO as GPIO
from config import PIN_FAN_PWM, PIN_FAN_TACH, PWM_FREQUENCY


class FanController:
    """Contrôle PWM du ventilateur + mesure RPM via polling TACH."""

    def __init__(self):
        GPIO.setup(PIN_FAN_PWM, GPIO.OUT)
        GPIO.setup(PIN_FAN_TACH, GPIO.IN, pull_up_down=GPIO.PUD_UP)
        self.pwm = GPIO.PWM(PIN_FAN_PWM, PWM_FREQUENCY)
        self.pwm.start(0)
        self._duty = 0.0
        self._rpm = 0
        threading.Thread(target=self._rpm_loop, daemon=True).start()

    def _rpm_loop(self):
        last = GPIO.input(PIN_FAN_TACH)
        count = 0
        t0 = time.time()
        while True:
            cur = GPIO.input(PIN_FAN_TACH)
            if cur == 0 and last == 1:  # front descendant
                count += 1
            last = cur
            now = time.time()
            if now - t0 >= 1.0:
                self._rpm = count * 30  # 2 impulsions/tour → ×60/2
                count = 0
                t0 = now
            time.sleep(0.001)

    def set_speed(self, duty):
        duty = max(0.0, min(100.0, float(duty)))
        if duty == 0.0:
            # Forcer le pin LOW — évite les micro-impulsions du soft PWM à 0%
            self.pwm.ChangeDutyCycle(0)
            GPIO.output(PIN_FAN_PWM, GPIO.LOW)
        else:
            self.pwm.ChangeDutyCycle(duty)
        self._duty = duty

    @property
    def duty(self):
        return self._duty

    @property
    def rpm(self):
        return self._rpm

    def stop(self):
        self.set_speed(0)

    def cleanup(self):
        self.pwm.stop()

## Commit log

2026-09-29 Logiciel d'acquisition et de supervision de la soufflerie pédagogique
    Serveur web et boucles d'acquisition du Raspberry Pi (ventilateur, force,
    caméra, capteurs I²C), avec un export de session réel en exemple.
    [session-2026-05-28.csv]
2026-09-30 Documenter la soufflerie et ajouter les fichiers de reproduction
    [Assemblage V2 - 120x12x38 fan.step, Assemblage V2 - Alvéoles concentration.step, Assemblage V2 - Alvéoles diffuseur.step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]
2026-09-30 Présenter les modèles 3D et l'électronique simplement
2026-09-30 Ajouter la vidéo YouTube de présentation au README
2026-10-01 Retirer les attributions personnelles du projet
